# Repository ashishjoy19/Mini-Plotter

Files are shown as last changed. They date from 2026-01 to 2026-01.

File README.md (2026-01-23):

# Electronics 

# ⚡ Mini Plotter V2 – Electronics Documentation

## Overview

This document covers **the electronics subsystem** of the Mini Plotter V project.

It is intended as a **reference for coworkers, fabrication, debugging, and replication** of the electronics and PCB.

---

## Scope

### Included
- PCB design reference
- Power architecture
- Microcontroller pin mapping
- Stepper driver connections
- Peripheral interfaces

**Board Details**

| Parameter | Value |
|---|---|
| PCB Name | Mini Plotter V2 – Electronics |
| Layers | 2 |
| Thickness | 1.6 mm |
| Copper Weight | 1 oz |
| Assembly | Through-hole + SMD |
| Logic Voltage | 3.3V |
| Motor Voltage | 5V DC |

## Power Architecture

### Power Input
- External DC input - USB C (Power only)
- Recommended supply: **5V**

### Voltage Rails
- **Motor Rail:** Direct from input to stepper drivers
- **Logic Rail:** Regulated 3.3V for MCU and peripherals

### Electrical Notes

⚠️ **Important**
- Power supply must handle motor current peaks
- Logic and motor grounds are common
- Do not connect or disconnect motors while powered

---

## MCU Pin Mapping

## GPIO Pin Mapping (Grouped)

### Motor 1 (Stepper)
| Label | GPIO |
|-----|---|
| IN1 | GPIO 23 |
| IN2 | GPIO 22 |
| IN3 | GPIO 21 |
| IN4 | GPIO 19 |

### Motor 2 (Stepper)
| Label | GPIO |
|-----|---|
| IN5 | GPIO 18 |
| IN6 | GPIO 17 |
| IN7 | GPIO 16 |
| IN8 | GPIO 4 |

### Servo Motor
| Label | GPIO |
|---|---|
| SIGNAL | GPIO 13 |
| VCC | 5V |
| GND | GND |

### Limit Switches
| Switch | Signal GPIO | Ground |
|---|---|---|
| X Limit | GPIO 27 | GND |
| Y Limit | GPIO 14 | GND |

---

# ⚡ ESP32-WROOM-32E – PCB Design & Boot Guidelines

This document provides **electronics design guidelines** for using the **ESP32-WROOM-32E** module in custom PCBs.

It focuses on:
- Boot and flashing requirements
- Strapping pins and default states
- Pins to avoid or use with caution
- Minimum required external circuitry
- PCB layout considerations

---

## ESP32-WROOM-32E Overview

- MCU: ESP32 (dual-core Xtensa LX6)
- Operating Voltage: **3.3V**
- Wi-Fi + Bluetooth on-module
- Integrated antenna (keep-out required)

⚠️ **All GPIOs are 3.3V only. Do NOT apply 5V.**

---

## Minimum Circuit for Boot & Flash

::contentReference[oaicite:0]{index=0}

### Mandatory Connections

| Pin | Requirement |
|----|---|
| 3V3 | Stable 3.3V supply (≥ 600 mA peak) |
| GND | Solid ground connection |
| EN | Pulled HIGH (via 10kΩ) |
| IO0 | Pulled HIGH (via 10kΩ) |
| TX0 (GPIO1) | UART TX for flashing |
| RX0 (GPIO3) | UART RX for flashing |

---

## Boot & Flash Logic

### Boot Mode Selection

| IO0 State | Boot Mode |
|---|---|
| HIGH | Normal boot (flash) |
| LOW | UART download (flashing) |

To flash firmware:
- **IO0 = LOW**
- **EN toggled LOW → HIGH (reset)**

---

## Strapping Pins (CRITICAL)

These pins are sampled **at reset**.  
Incorrect levels will prevent booting.

| GPIO | Default State | Function |
|----|---|---|
| GPIO0 | Pull-up | Boot mode select |
| GPIO2 | Pull-down | Must be LOW at boot |
| GPIO4 | Pull-down | Boot config |
| GPIO5 | Pull-up | Boot config |
| GPIO12 | Pull-down | Flash voltage select |
| GPIO15 | Pull-up | Boot config |

⚠️ **Do not drive these pins externally at boot unless you know the impact.**

---

## Pin Usage Guidelines

### Pins to Avoid (or Use Carefully)

| GPIO | Reason |
|----|---|
| GPIO6–11 | Connected to internal flash (DO NOT USE) |
| GPIO0 | Boot mode pin |
| GPIO2 | Must be LOW during boot |
| GPIO12 | Affects flash voltage |
| GPIO15 | Boot strapping pin |

---

### Recommended Safe GPIOs

| GPIO | Notes |
|----|---|
| GPIO4 | Safe after boot |
| GPIO5 | Safe after boot |
| GPIO16–19 | General purpose |
| GPIO21–23 | I²C / SPI friendly |
| GPIO25–27 | ADC capable |
| GPIO32–33 | ADC + low power |
| GPIO34–39 | Input-only (ADC) |

---

## Pull-Up / Pull-Down Requirements

### Required External Resistors

| Pin | Recommended |
|----|---|
| EN | 10kΩ pull-up to 3.3V |
| IO0 | 10kΩ pull-up |
| GPIO2 | 10kΩ pull-down |
| GPIO12 | 10kΩ pull-down |
| GPIO15 | 10kΩ pull-up |

⚠️ Internal pulls exist but **external resistors improve reliability**.

---

## Reset & Auto-Flash Circuit (Recommended)

For USB-UART auto programming:

| ESP32 Pin | USB-UART Signal |
|---|---|
| EN | DTR (via transistor) |
| IO0 | RTS (via transistor) |
| RX0 | TXD |
| TX0 | RXD |

This allows flashing via:
- Arduino IDE
- ESP-IDF
- PlatformIO

---

## Power Supply Design Notes

- Use **LDO or buck regulator** capable of **600–800 mA**
- Place **10µF + 0.1µF decoupling capacitors** close to 3V3 pin
- Keep power traces wide and short

⚠️ Brownouts are the #1 cause of ESP32 instability.

---

## Antenna & RF Layout Rules

⚠️ **Very Important**

- Keep copper **clear under antenna**
- No ground pours or traces under antenna area
- Follow Espressif keep-out recommendations
- Place module at PCB edge if possible

---

## Common Design Mistakes

❌ Powering ESP32 from 5V  
❌ Using GPIO6–11  
❌ Driving strapping pins at boot  
❌ Weak 3.3V regulator  
❌ Traces under antenna  

---

## Recommended Bring-Up Checklist

1. Verify 3.3V rail (no load)
2. Check EN pulled HIGH
3. Check IO0 pulled HIGH
4. Reset → observe serial output
5. Pull IO0 LOW → reset → flash test firmware

---

## Reference

- ESP32-WROOM-32E Datasheet
- Espressif Hardware Design Guidelines

---

## Notes

This document is intended for **PCB designers and electronics engineers** working with ESP32-WROOM-32E in custom hardware.

Keep this file updated if pin usage or constraints change.

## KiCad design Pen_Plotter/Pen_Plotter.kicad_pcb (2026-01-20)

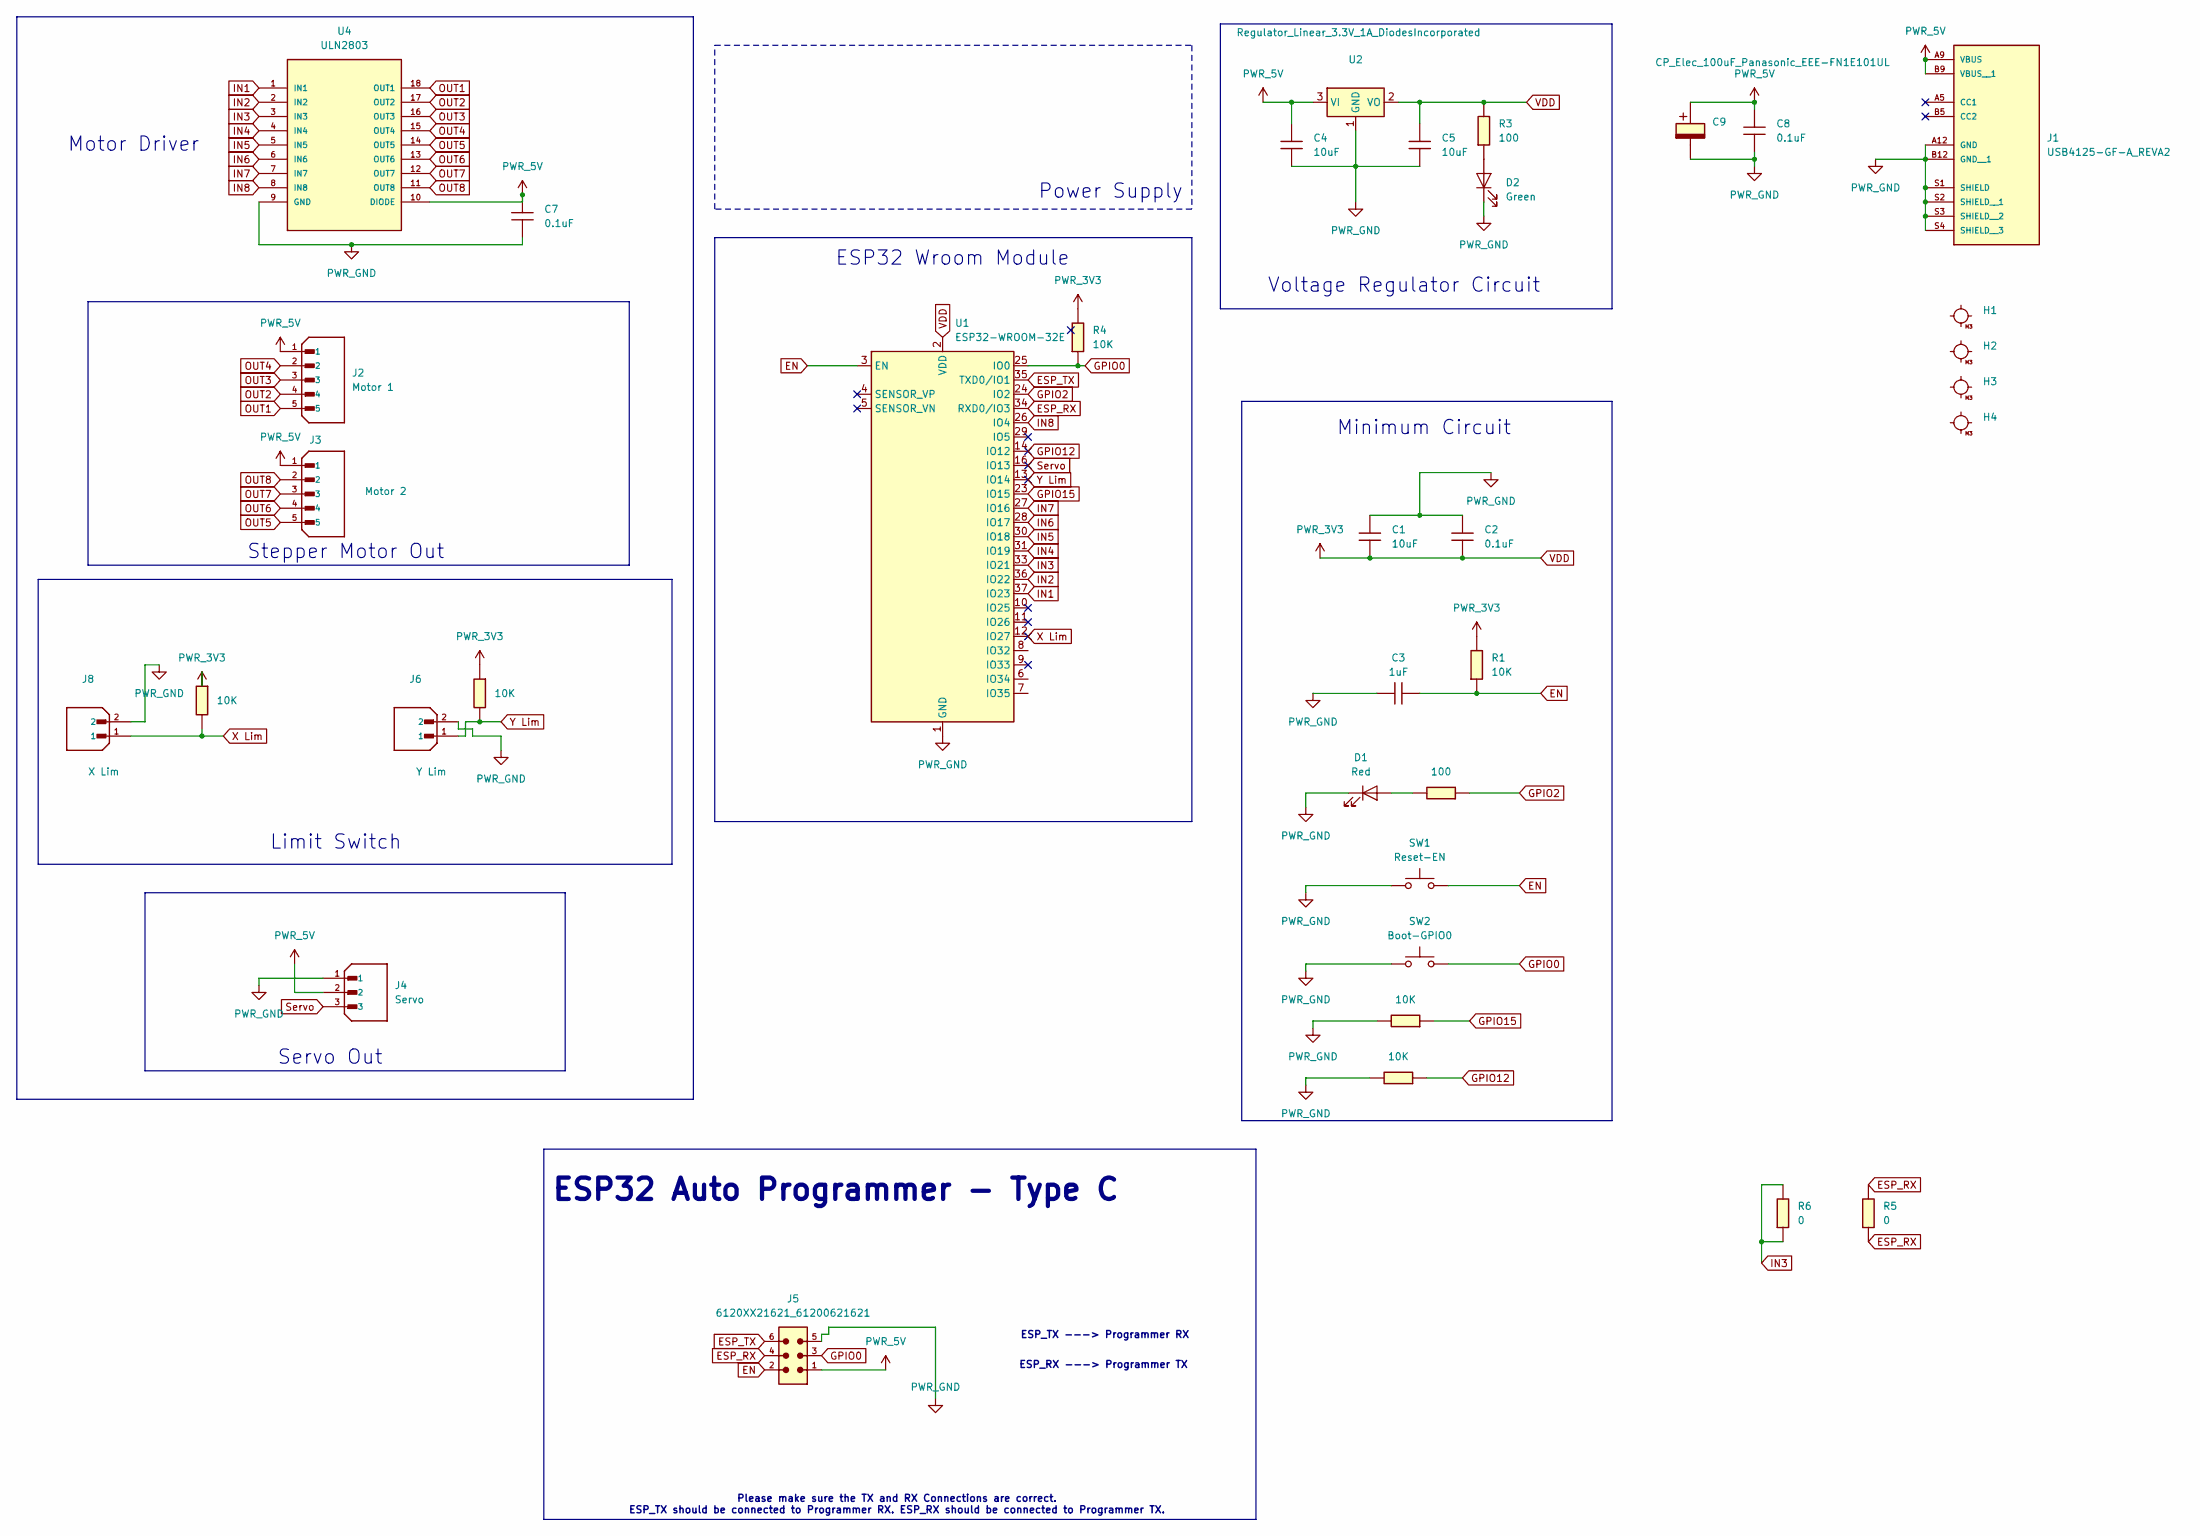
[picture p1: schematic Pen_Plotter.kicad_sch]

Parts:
C1, C4, C5: 10uF; C_1206
C2, C7, C8: 0.1uF; C_1206
C3: 1uF; C_1206
C9: CP_Elec_100uF_Panasonic_EEE-FN1E101UL
D1: Red; LED_1206
D2: Green; LED_1206
H1, H2, H3, H4: MountingHole_M3
J1: USB4125-GF-A_REVA2; GCT_USB4125-GF-A_REVA2; PARTREV Rev A2
J2: Motor 1; JST_B5B-XH-A; PARTREV 7/4/21
J3: Motor 2; JST_B5B-XH-A; PARTREV 7/4/21
J4: Servo; JST_B3B-XH-A; PARTREV 7/4/21
J5: 6120XX21621_61200621621; 61200621621
J6: Y Lim; JST_B2B-XH-A_LF__SN_; PARTREV N/A
J8: X Lim; JST_B2B-XH-A_LF__SN_; PARTREV N/A
R1, R4, R8, R9, R10, R11: 10K; R_1206
R2, R3: 100; R_1206
R5, R6: 0; R_1206
SW1: Reset-EN; Button_Omron_B3SN_6.0x6.0mm
SW2: Boot-GPIO0; Button_Omron_B3SN_6.0x6.0mm
U1: ESP32-WROOM-32E; ESP32-WROOM-32D
U2: Regulator_Linear_3.3V_1A_DiodesIncorporated; SOT-223-3_TabPin2
U4: ULN2803; SO18L

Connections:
EN: C3.1, J5.2, R1.2, SW1.2, U1.3 (EN)
ESP_RX: J5.4, R5.1, R5.2, U1.34 (RXD0/IO3)
ESP_TX: J5.6, U1.35 (TXD0/IO1)
GPIO0: J5.3, R4.2, SW2.2, U1.25 (IO0)
GPIO2: R2.2, U1.24 (IO2)
GPIO12: R11.2, U1.14 (IO12)
GPIO15: R8.2, U1.23 (IO15)
IN1: U1.37 (IO23), U4.1 (IN1)
IN2: U1.36 (IO22), U4.2 (IN2)
IN3: R6.1, R6.2, U1.33 (IO21), U4.3 (IN3)
IN4: U1.31 (IO19), U4.4 (IN4)
IN5: U1.30 (IO18), U4.5 (IN5)
IN6: U1.28 (IO17), U4.6 (IN6)
IN7: U1.27 (IO16), U4.7 (IN7)
IN8: U1.26 (IO4), U4.8 (IN8)
unnamed: D1.2 (A), R2.1
unnamed: D2.2 (A), R3.2
OUT1: J2.5, U4.18 (OUT1)
OUT2: J2.4, U4.17 (OUT2)
OUT3: J2.3, U4.16 (OUT3)
OUT4: J2.2, U4.15 (OUT4)
OUT5: J3.5, U4.14 (OUT5)
OUT6: J3.4, U4.13 (OUT6)
OUT7: J3.3, U4.12 (OUT7)
OUT8: J3.2, U4.11 (OUT8)
PWR_5V: C4.1, C7.1, C8.1, C9.1, J1.A9 (VBUS), J1.B9 (VBUS__1), J2.1, J3.1, J4.2, J5.1, U2.3 (VI), U4.10 (DIODE)
PWR_GND: C1.1, C2.1, C3.2, C4.2, C5.2, C7.2, C8.2, C9.2, D1.1 (K), D2.1 (K), J1.A12 (GND), J1.B12 (GND__1), J1.S1 (SHIELD), J1.S2 (SHIELD__1), J1.S3 (SHIELD__2), J1.S4 (SHIELD__3), J4.1, J5.5, J6.2, J8.2, R8.1, R11.1, SW1.1, SW2.1, U1.1 (GND), U1.15 (GND), U1.38 (GND), U1.39 (GND), U2.1 (GND), U4.9 (GND)
Servo: J4.3, U1.16 (IO13)
VDD: C1.2, C2.2, C5.1, R1.1, R3.1, R4.1, R9.2, R10.2, U1.2 (VDD), U2.2 (VO)
X Lim: J8.1, R10.1, U1.12 (IO27)
Y Lim: J6.1, R9.1, U1.13 (IO14)

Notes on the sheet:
ESP_TX ---> Programmer RX
Limit Switch
ESP_RX ---> Programmer TX
Minimum Circuit
ESP32 Auto Programmer - Type C
Stepper Motor Out
Power Supply
Please make sure the TX and RX Connections are correct. ESP_TX should be connected to Programmer RX. ESP_RX should be connected to Programmer TX.
Servo Out
Motor Driver
Voltage Regulator Circuit
ESP32 Wroom Module

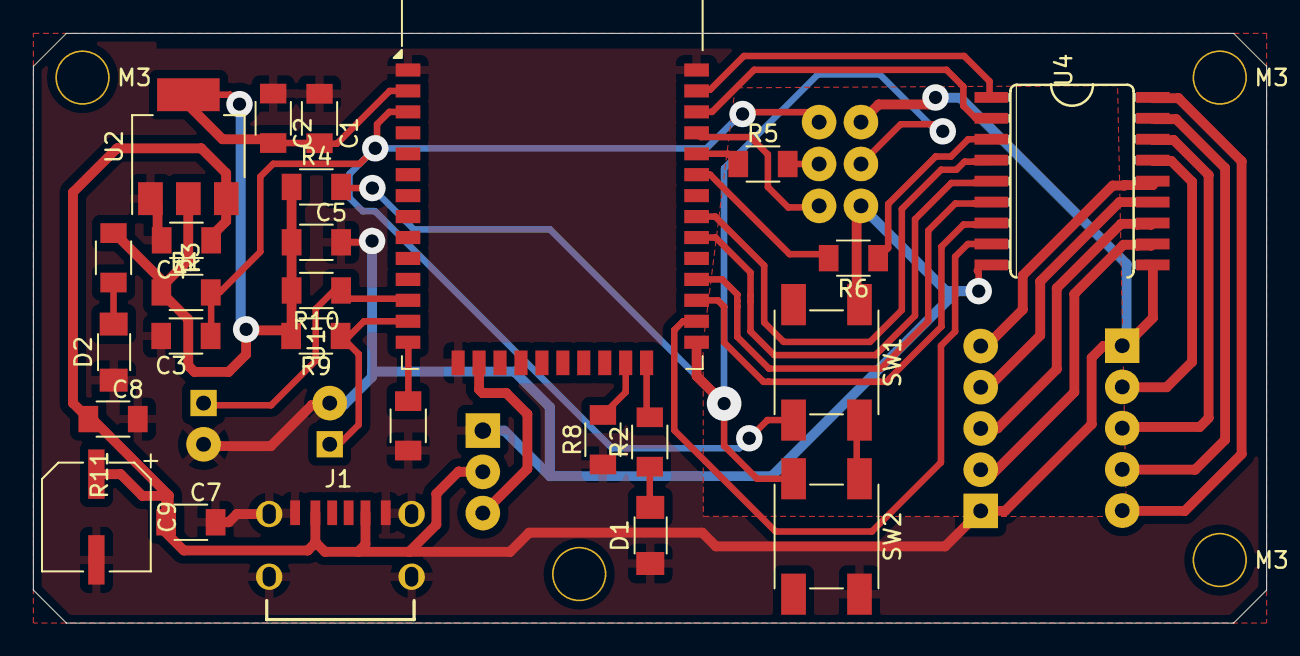
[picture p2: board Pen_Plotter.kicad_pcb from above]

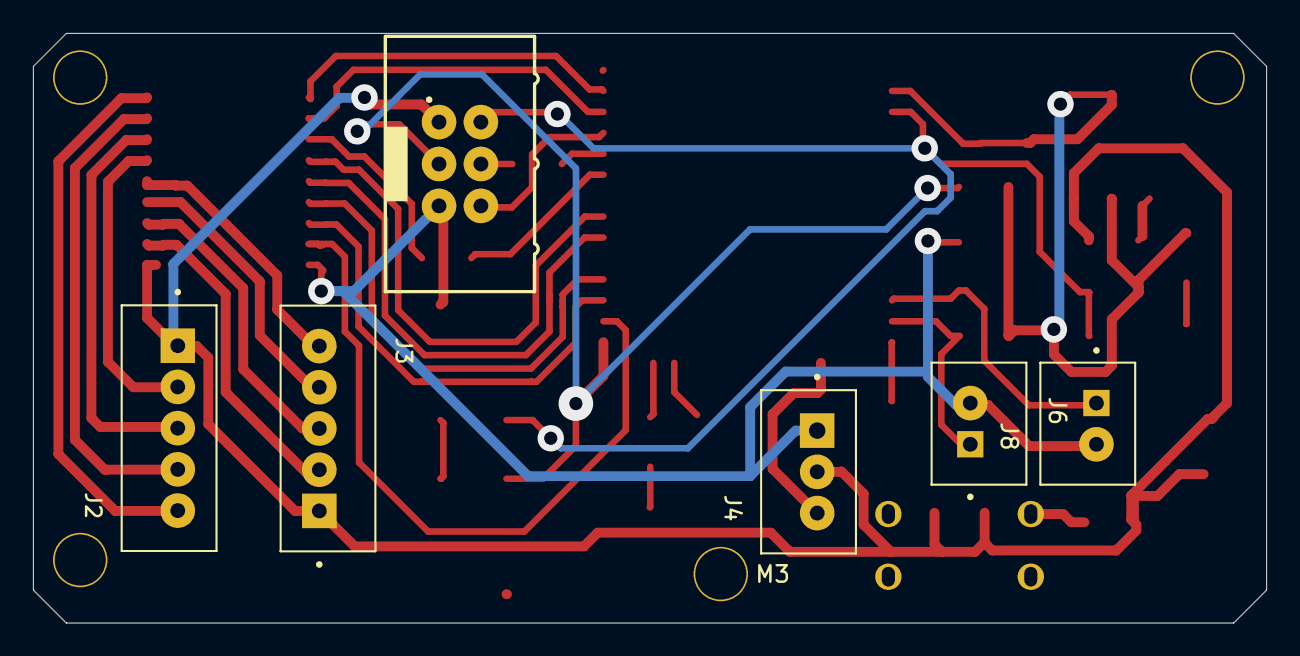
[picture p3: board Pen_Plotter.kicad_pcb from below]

Board: 2 copper layers, 74.8 x 35.8 mm, 36 parts (7 on the bottom side), 31 nets.

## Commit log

2026-01-05 schematic v1
    [Pen_Plotter.kicad_pcb, Pen_Plotter.kicad_sch]
2026-01-05 Added some text
    [Pen_Plotter.kicad_sch]
2026-01-06 6 January
    [Pen_Plotter.kicad_pcb, Pen_Plotter.kicad_sch]
2026-01-06 Wired THT Components
    [Pen_Plotter.kicad_pcb, Pen_Plotter.kicad_sch]
2026-01-06 Version with Auto Programmer, USBC and CH340 IC
    [Pen_Plotter.kicad_pcb, Pen_Plotter.kicad_sch]
2026-01-06 Schematic Excluded USBC, CH340IC, Autoprogrammer PCB: Removed components
    [Pen_Plotter.kicad_pcb, Pen_Plotter.kicad_sch]
2026-01-13 PCB for ESP UCap
    [Pen_Plotter.kicad_pcb, Pen_Plotter.kicad_sch]
2026-01-13 Mini Plotter PCB 13
    [Pen_Plotter.kicad_pcb, Pen_Plotter.kicad_sch]
2026-01-13 added gerber files
    [Pen_Plotter-B_Cu.gbr, Pen_Plotter-B_Mask.gbr, Pen_Plotter-B_Paste.gbr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]
2026-01-17 First PCB Final - Problems with RX-TX
    [Pen_Plotter.kicad_pcb, Pen_Plotter.kicad_sch]
2026-01-17 PCB _ TX and RX Corrected
    [Pen_Plotter.kicad_pcb, Pen_Plotter.kicad_sch]
2026-01-17 Gitlab and Github push test
    [Pen_Plotter.kicad_sch]
2026-01-17 second push test
    [Pen_Plotter.kicad_sch]
2026-01-17 PCB V2.1
    [Pen_Plotter.kicad_pcb, Pen_Plotter.kicad_sch]
2026-01-19 Inverted IDC Connector position and thickened traces
    [Pen_Plotter.kicad_pcb, Pen_Plotter.kicad_sch]
2026-01-19 CAD Components added
    [Pen_Plotter.kicad_pcb]
2026-01-19 FInal PCB V@, ready for milling
    [Pen_Plotter.kicad_pcb]
2026-01-19 PCB V2 Draft
    [Pen_Plotter.kicad_sch]
2026-01-20 Final PCB Milling done; Retraced traces to top
    [Pen_Plotter.kicad_pcb]
2026-01-23 updated readme file
    [Pen_Plotter.kicad_sch]
